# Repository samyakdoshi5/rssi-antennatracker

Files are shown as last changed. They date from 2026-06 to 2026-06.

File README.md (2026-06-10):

# RX5808 Diversity Antenna Tracker

Arduino firmware, PCB drafts, and printable enclosure files for an RX5808/RX58xx diversity receiver adapted into an RSSI-based pan tracker. The active firmware targets a 128x32 SSD1306 OLED and drives a continuous-rotation servo from the calibrated RSSI difference between two directional antennas.

## Repository Layout

| Path | Contents |
| --- | --- |
| `code/rx5808-pro-diversity-2.0/` | Active Arduino firmware and bundled legacy support libraries. |
| `code/rx5808-pro-diversity-2.0/rx5808-pro-diversity/` | Main sketch and source files. Open `rx5808-pro-diversity.ino` in the Arduino IDE. |
| `code/buttontest/` | Small standalone sketch for checking button wiring. |
| `pcb (draft)/` | Draft KiCad project and exported Gerber/drill files. |
| `v1/` to `v5/` | Mechanical enclosure revisions. `v5/` is the newest STL set. |

## Hardware

- Arduino-compatible AVR board
- Two RX5808/RX58xx receiver modules
- 128x32 SSD1306 I2C OLED
- Continuous-rotation 360 servo for pan movement
- Three firmware buttons: Up, Down, Mode
- Active buzzer
- Two directional antennas, with receiver A mounted left and receiver B mounted right

## Pin Map

| Function | Pin |
| --- | --- |
| Button Up | `2` |
| Button Down | `3` |
| Button Mode | `4` |
| Buzzer | `6` |
| Tracker servo | `7` |
| SPI data | `10` |
| SPI slave select | `11` |
| SPI clock | `12` |
| Board LED | `13` |
| Receiver A LED/control | `A0` |
| Receiver B LED/control | `A1` |
| Receiver A RSSI | `A7` |
| Receiver B RSSI | `A6` |

## Firmware Configuration

Main configuration lives in:

```text
code/rx5808-pro-diversity-2.0/rx5808-pro-diversity/settings.h
```

Current enabled options:

```cpp
#define OLED_128x32_ADAFRUIT_SCREENS
#define RX5808
#define USE_DIVERSITY
#define USE_DIVERSITY_FAST_SWITCHING
#define USE_SERIAL_OUT
#define USE_LBAND
```

The old screensaver state has been removed, and the UI has been compressed for the 128x32 OLED.

## Build Notes

Open this sketch in the Arduino IDE:

```text
code/rx5808-pro-diversity-2.0/rx5808-pro-diversity/rx5808-pro-diversity.ino
```

Required Arduino libraries:

- `Adafruit_SSD1306`
- `Adafruit_GFX`
- `Servo`

Bundled legacy libraries for TVout/pollserial are kept under `code/rx5808-pro-diversity-2.0/libraries/`. The current OLED build does not use TVout screens, but the files remain in the project history.

The sketch uses placement `new` through the standard `<new>` header. Do not add a custom placement `operator new`; newer Arduino cores already provide it and duplicate definitions can fail linking.

## Controls

- Hold `MODE` to open the menu.
- In the menu, use `UP` and `DOWN` to move between items.
- Short-press `MODE` to select the highlighted item.
- In tracker mode, short-press `MODE` to stop/recenter the servo command.

## Modes

- `Search`: normal channel search view.
- `Band Scan`: scans channels and draws RSSI history.
- `Tracker`: compares calibrated A/B RSSI and drives the pan servo.
- `Settings`: RSSI calibration entry point.

## Tracker Mode

Tracker mode assumes:

- Receiver `A` antenna points left.
- Receiver `B` antenna points right.
- A stronger calibrated `A` RSSI means the target is left.
- A stronger calibrated `B` RSSI means the target is right.

The tracker compares calibrated RSSI percentages, not raw ADC readings. This matters because two receiver modules often have different raw RSSI ranges.

The tracker display shows:

```text
A:cal/raw    B:cal/raw
winner       channel
PWM:us       direction graphic
```

Example:

```text
A:72/184     B:65/211
A LEFT       R1
PWM:1560     <----
```

## RSSI Calibration

Run RSSI calibration from `Settings` before using tracker mode.

The calibration stores independent min/max values for both modules:

- `rssiAMin`, `rssiAMax`
- `rssiBMin`, `rssiBMax`

The receiver code maps raw readings into calibrated `0..100` RSSI values. Tracker mode uses those calibrated values for decisions and only displays raw values for diagnosis.

## Servo Control

The tracker is set up for a continuous-rotation servo using microsecond pulses:

```cpp
#define TRACKER_SERVO_STOP_US 1500
#define TRACKER_SERVO_LEFT_MIN_US 1505
#define TRACKER_SERVO_LEFT_MAX_US 1850
#define TRACKER_SERVO_RIGHT_MIN_US 1495
#define TRACKER_SERVO_RIGHT_MAX_US 1150
```

Tune `TRACKER_SERVO_STOP_US` first. If the servo creeps while stopped, adjust it slightly, for example to `1490` or `1510`.

The min values define the deadband edge. Once the tracker decides to move, it will command at least:

- `TRACKER_SERVO_LEFT_MIN_US` when moving left
- `TRACKER_SERVO_RIGHT_MIN_US` when moving right

The max values cap top speed in each direction.

## Tracker Tuning

Main tracker parameters are in `settings.h`.

```cpp
#define TRACKER_RSSI_MOVE_THRESHOLD 10
#define TRACKER_RSSI_STOP_THRESHOLD 5
#define TRACKER_MOVE_INTERVAL 20
#define TRACKER_MAX_SPEED_OFFSET_US 350
#define TRACKER_SERVO_SMOOTH_INTERVAL 5
#define TRACKER_SERVO_SMOOTH_STEP_US 70
```

- `TRACKER_RSSI_MOVE_THRESHOLD`: calibrated RSSI percent difference needed to start moving.
- `TRACKER_RSSI_STOP_THRESHOLD`: calibrated RSSI percent difference where movement stops. Keep below the move threshold for hysteresis.
- `TRACKER_MOVE_INTERVAL`: PID target-speed update interval in ms.
- `TRACKER_MAX_SPEED_OFFSET_US`: max speed offset from neutral before direction caps.
- `TRACKER_SERVO_SMOOTH_INTERVAL`: how often the output pulse slews toward the target.
- `TRACKER_SERVO_SMOOTH_STEP_US`: max microsecond change per smoothing tick.

PID values:

```cpp
#define TRACKER_PID_KP 120
#define TRACKER_PID_KI 0
#define TRACKER_PID_KD 80
#define TRACKER_PID_SCALE 16
#define TRACKER_PID_INTEGRAL_MAX 80
```

- Raise `KP` for faster response to RSSI error.
- Keep `KI` at `0` unless you need persistent bias correction.
- Raise `KD` to damp overshoot when the error is shrinking.
- Raise `TRACKER_PID_SCALE` to make the whole PID output less aggressive.

## Serial Debug

Serial RSSI output is enabled:

```cpp
#define USE_SERIAL_OUT
```

Open Serial Monitor at `250000` baud. Output is tab-separated:

```text
channel    rssiA    rssiA_raw    rssiB    rssiB_raw
```

## Mechanical Files

The enclosure revisions are organized as `v1/` through `v5/`. The newest revision, `v5/`, contains:

- `mainshell.STL`
- `baselid.STL`
- `articulatedtop.STL`
- `antennaframe.STL`
- `hingepin.STL`

Earlier revisions include additional SolidWorks source files and intermediate STL/3MF exports.

## PCB Files

`pcb (draft)/` contains a draft KiCad project:

- `main.kicad_pro` — Project file
- `main.kicad_sch` — Schematic
- `main.kicad_pcb` — PCB layout

Treat this as a draft design until it has been checked against the latest mechanical and wiring changes. Manufacturing files (Gerber, drill, etc.) have not yet been exported.

## Quick Tuning Order

1. Flash `code/buttontest/buttontest.ino` if you need to verify button wiring.
2. Flash the main tracker sketch.
3. Tune `TRACKER_SERVO_STOP_US` until the servo does not creep.
4. Set `TRACKER_SERVO_LEFT_MIN_US` and `TRACKER_SERVO_RIGHT_MIN_US` just outside the servo deadband.
5. Run RSSI calibration.
6. If it chases noise, raise `TRACKER_RSSI_MOVE_THRESHOLD` and `TRACKER_RSSI_STOP_THRESHOLD`.
7. If it reacts too slowly, raise `TRACKER_PID_KP` or `TRACKER_MAX_SPEED_OFFSET_US`.
8. If it overshoots, raise `TRACKER_PID_KD` or lower `TRACKER_PID_KP`.

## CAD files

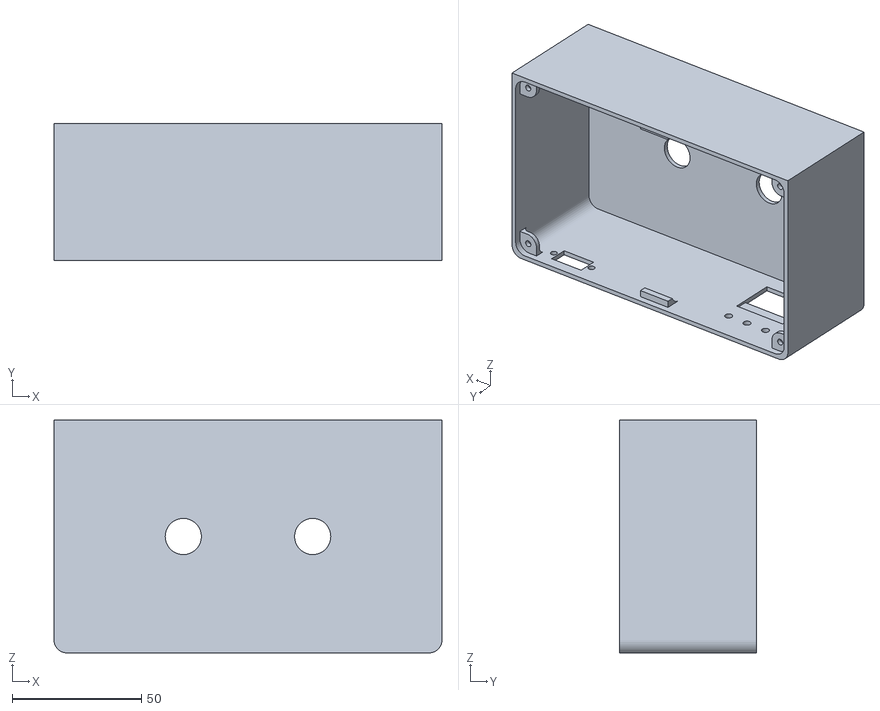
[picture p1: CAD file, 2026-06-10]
v5/mainshell.STL
150.0 x 53.0 x 90.0

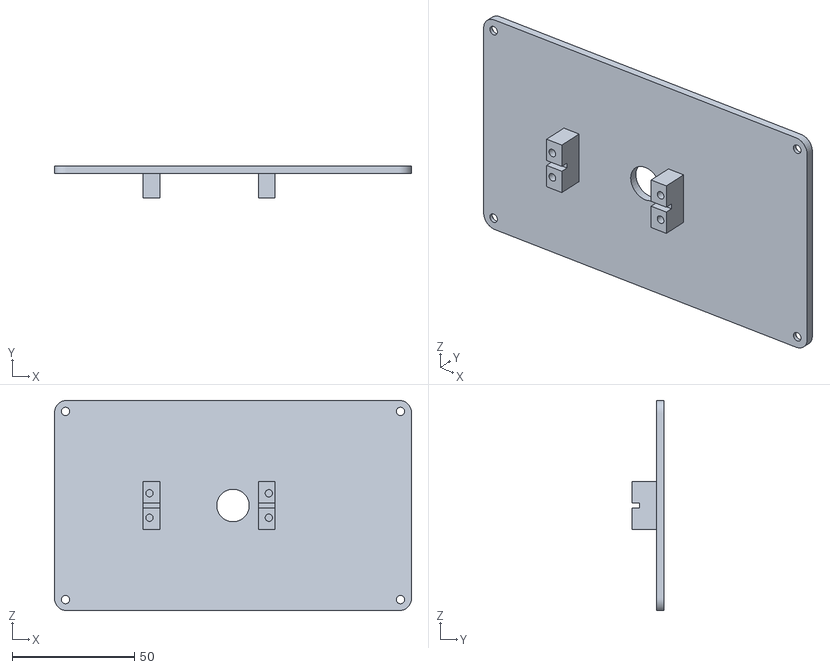
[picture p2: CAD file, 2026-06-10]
v5/baselid.STL
146.0 x 13.0 x 86.0

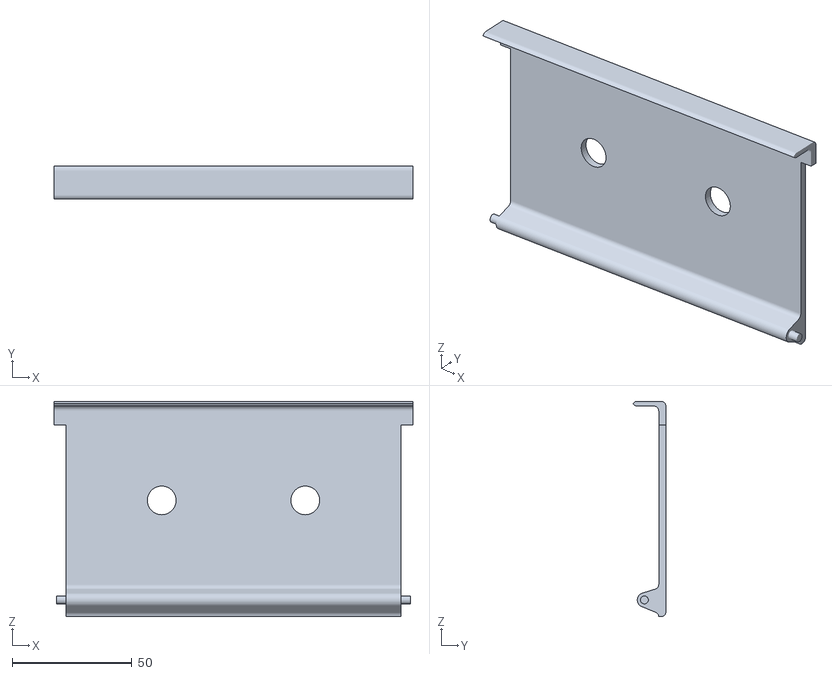
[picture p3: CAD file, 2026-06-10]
v5/articulatedtop.STL
150.0 x 13.7 x 90.0

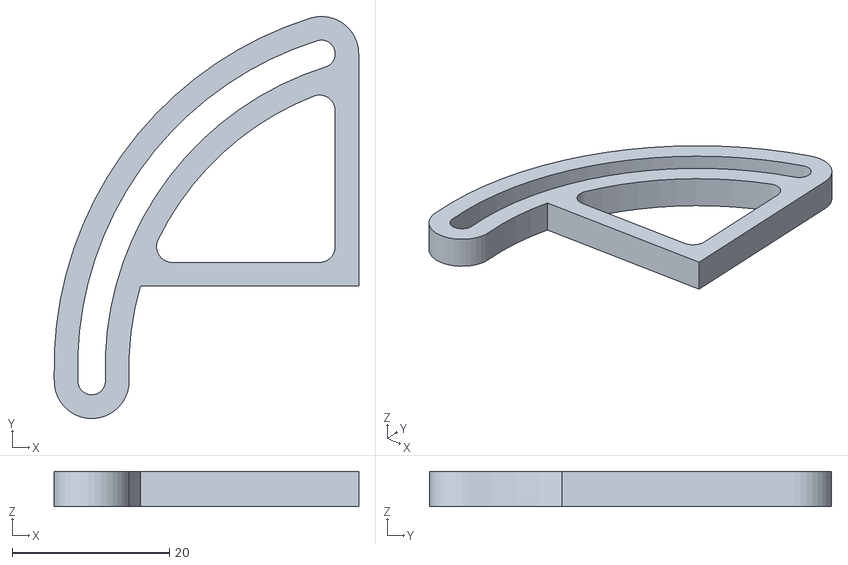
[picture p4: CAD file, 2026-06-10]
v5/hingepin.STL
38.7 x 51.1 x 4.50

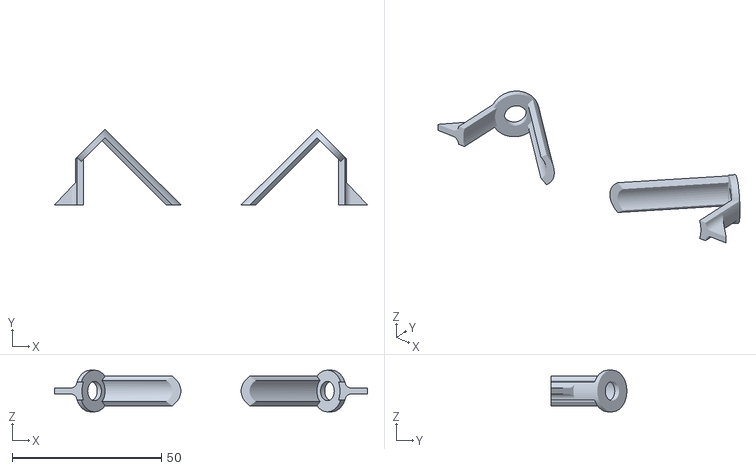
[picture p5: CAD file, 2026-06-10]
v5/antennaframe.STL
105.0 x 25.4 x 14.0

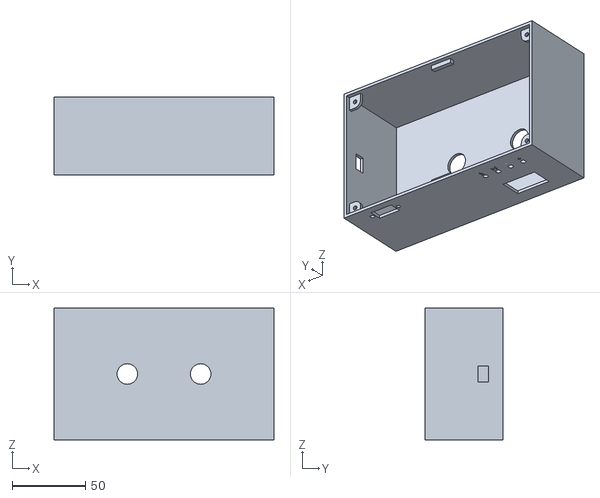
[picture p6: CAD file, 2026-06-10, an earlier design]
v3/mainshell.STL
150.0 x 53.0 x 90.0

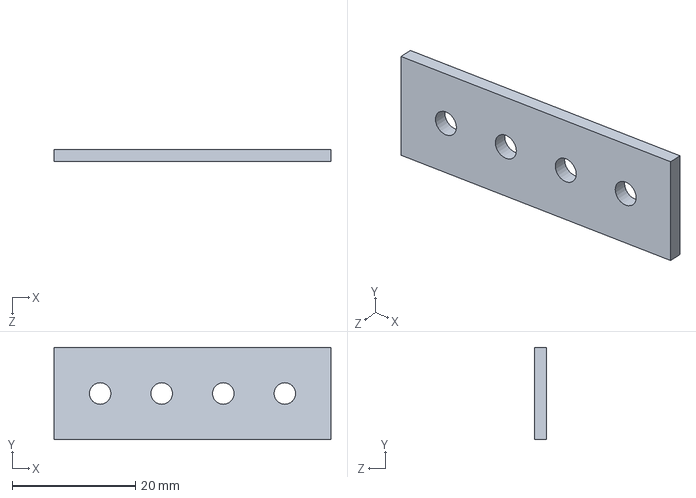
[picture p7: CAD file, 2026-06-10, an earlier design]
v1/buttonarray.SLDPRT
45.0 x 15.0 x 2.00 mm

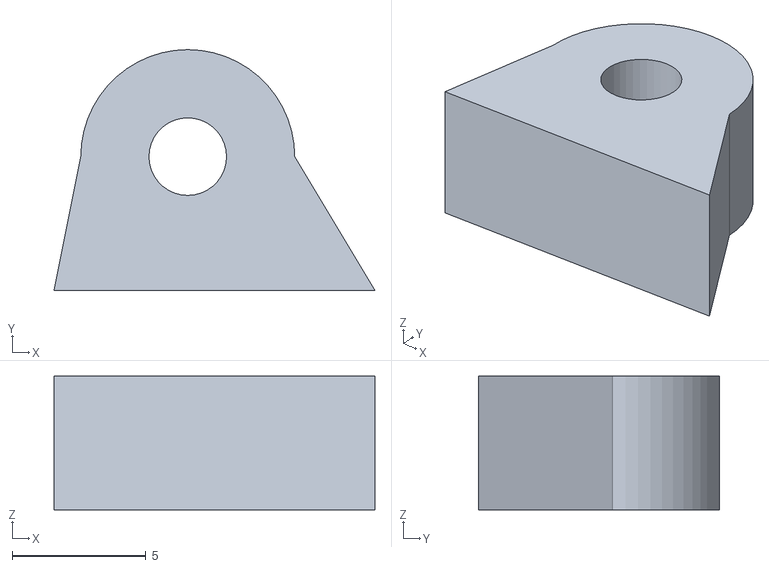
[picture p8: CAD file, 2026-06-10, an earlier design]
v2/hingepin.STL
12.0 x 9.00 x 5.00

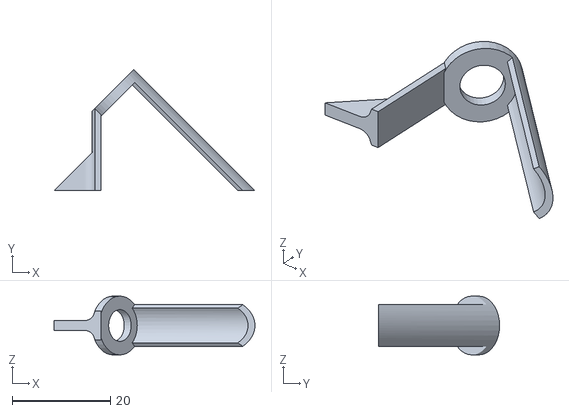
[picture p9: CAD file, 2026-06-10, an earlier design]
v3/antennaholder.STL
41.0 x 24.7 x 12.0

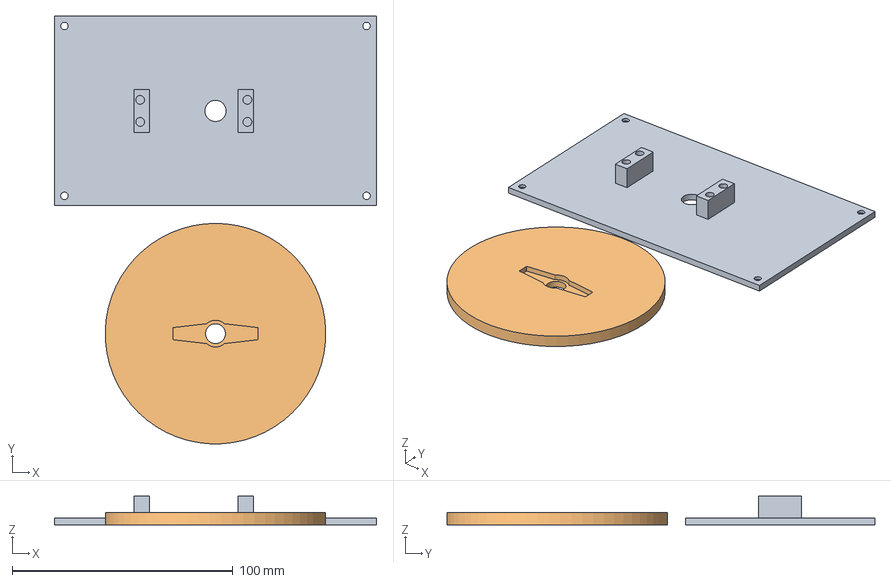
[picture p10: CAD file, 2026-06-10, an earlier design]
v4/base.3mf
146.0 x 194.0 x 13.0 mm
baselid.STL
base.STL

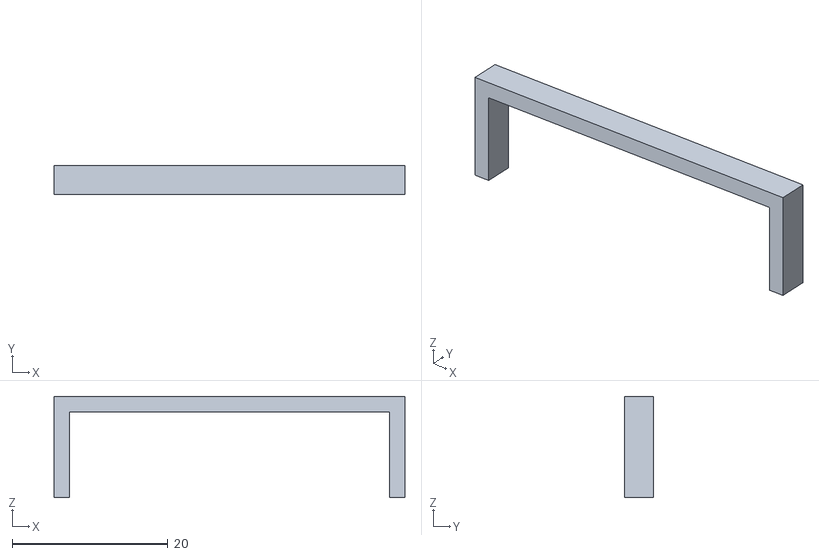
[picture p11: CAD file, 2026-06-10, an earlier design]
v2/buttonarrayriser.STL
45.0 x 3.75 x 13.0

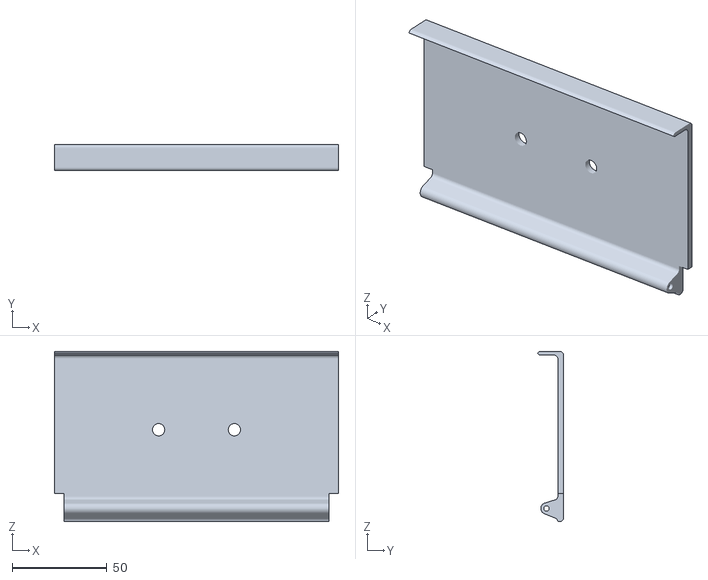
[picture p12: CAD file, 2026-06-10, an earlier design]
v2/articulatedtop.STL
150.0 x 13.7 x 90.0

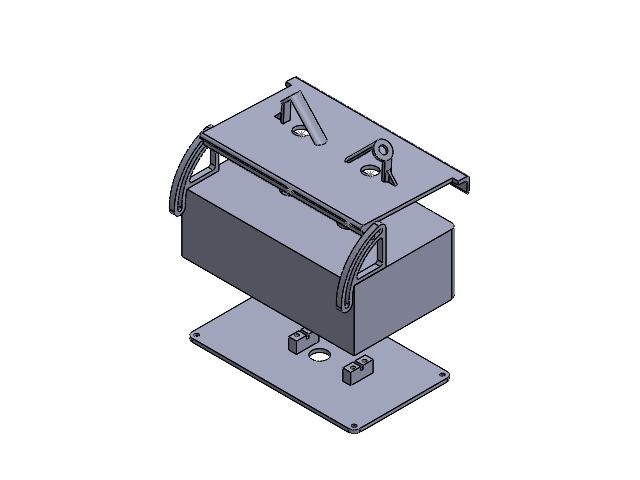
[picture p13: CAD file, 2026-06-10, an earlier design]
v1/assem.SLDASM
mainshell
baselid
articulatedtop
Display_OLED_0.96_128x64
hingepin x 2

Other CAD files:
v2/mainshell.STL
v1/mainshell.SLDPRT
v1/antennaframe.SLDPRT
v4/baselid.STL
v1/Body - Screen Border.SLDPRT.SLDPRT
v1/Body - Adhesive Pad.SLDPRT.SLDPRT
v1/Body - Back Panel.SLDPRT.SLDPRT
v1/Body - Black Tape.SLDPRT.SLDPRT
v1/Body - Flex Connector Bend.SLDPRT.SLDPRT
v1/Body - Flex Connector Terminals.SLDPRT.SLDPRT
v1/Body - Front Panel.SLDPRT.SLDPRT
v1/Body - PCB.SLDPRT.SLDPRT
v1/Body - Protective Foil.SLDPRT.SLDPRT
v1/Display_OLED_0.96_128x64.SLDPRT
v1/Extrude - Annular Rings.SLDPRT.SLDPRT
v1/accessory.SLDPRT
v1/articulatedtop.SLDPRT
v1/articulatedtop.STL
v1/baselid.SLDPRT
v1/baselid.STL
v1/buttonarrayriser.SLDPRT
v1/hingepin.SLDPRT
v1/hingepin.STL
v1/mainshell.STL
v2/baselid.STL
v2/buttonarray.STL
v2/servostandoff.SLDPRT
v2/servostandoff.STL
v3/articulatedtop.3mf
v3/articulatedtop.STL
v3/base.SLDPRT
v3/base.STL
v3/hingepin.STL
v4/base.STL

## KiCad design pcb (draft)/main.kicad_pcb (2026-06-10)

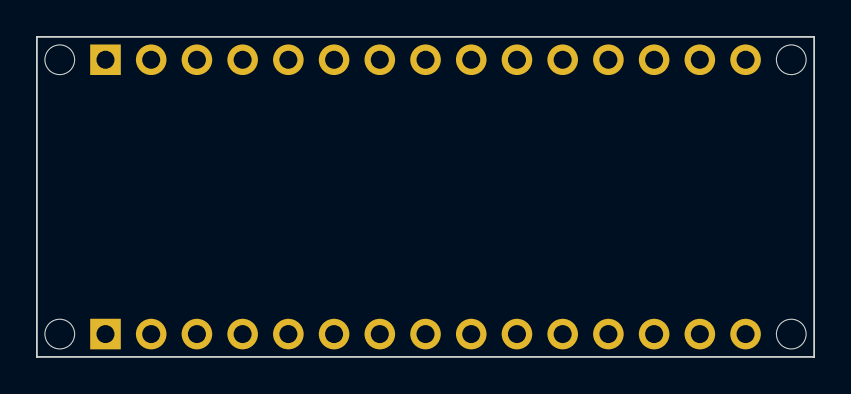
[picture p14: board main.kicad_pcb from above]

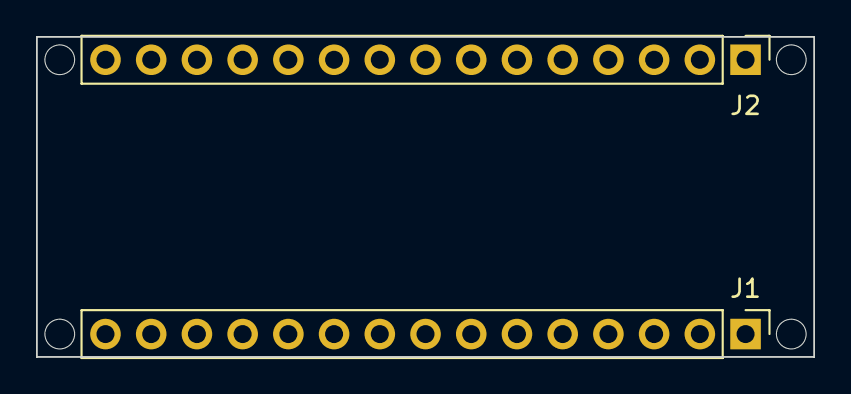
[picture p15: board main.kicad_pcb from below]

Board: 2 copper layers, 43.2 x 17.8 mm, 6 parts (2 on the bottom side), 2 nets, no tracks yet.

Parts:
J1: Analog; PinHeader_1x15_P2.54mm_Vertical
J2: Digital; PinHeader_1x15_P2.54mm_Vertical
MH1, MH2, MH3, MH4: MountingHole_65mil

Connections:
/~RESET: J1.13, J2.13
GND: J1.14, J2.12

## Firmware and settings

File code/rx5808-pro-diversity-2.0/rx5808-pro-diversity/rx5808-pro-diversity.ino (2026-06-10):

/*
 * SPI driver based on fs_skyrf_58g-main.c Written by Simon Chambers
 * TVOUT by Myles Metzel
 * Scanner by Johan Hermen
 * Inital 2 Button version by Peter (pete1990)
 * Refactored and GUI reworked by Marko Hoepken
 * Universal version my Marko Hoepken
 * Diversity Receiver Mode and GUI improvements by Shea Ivey
 * OLED Version by Shea Ivey
 * Seperating display concerns by Shea Ivey

The MIT License (MIT)

Copyright (c) 2015 Marko Hoepken

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
THE SOFTWARE IS PROVIDED "AS IS", WITHOUT WARRANTY OF ANY KIND, EXPRESS OR
IMPLIED, INCLUDING BUT NOT LIMITED TO THE WARRANTIES OF MERCHANTABILITY,
FITNESS FOR A PARTICULAR PURPOSE AND NONINFRINGEMENT. IN NO EVENT SHALL THE
AUTHORS OR COPYRIGHT HOLDERS BE LIABLE FOR ANY CLAIM, DAMAGES OR OTHER
LIABILITY, WHETHER IN AN ACTION OF CONTRACT, TORT OR OTHERWISE, ARISING FROM,
OUT OF OR IN CONNECTION WITH THE SOFTWARE OR THE USE OR OTHER DEALINGS IN THE
SOFTWARE.
*/


#include "settings.h"
#include "settings_internal.h"
#include "settings_eeprom.h"

#include "channels.h"
#include "receiver.h"
#include "receiver_spi.h"
#include "buttons.h"
#include "state.h"

#include "ui.h"


static void globalMenuButtonHandler(
    Button button,
    Buttons::PressType pressType
);


void setup()
{
    setupPins();

    // Enable buzzer and LED for duration of setup process.
    digitalWrite(PIN_LED, HIGH);
    digitalWrite(PIN_BUZZER, LOW);

    setupSettings();

    StateMachine::setup();
    Receiver::setup();
    Ui::setup();

    Receiver::setActiveReceiver(Receiver::ReceiverId::A);

    #ifdef USE_IR_EMITTER
        Serial.begin(9600);
    #endif
    #ifdef USE_SERIAL_OUT
        Serial.begin(250000);
    #endif

    // Setup complete.
    digitalWrite(PIN_LED, LOW);
    digitalWrite(PIN_BUZZER, HIGH);

    Buttons::registerChangeFunc(globalMenuButtonHandler);

    // Switch to initial state.
    StateMachine::switchState(StateMachine::State::SEARCH);
}

void setupPins() {
    pinMode(PIN_LED, OUTPUT);
    pinMode(PIN_BUZZER, OUTPUT);
    pinMode(PIN_BUTTON_UP, INPUT_PULLUP);
    pinMode(PIN_BUTTON_MODE, INPUT_PULLUP);
    pinMode(PIN_BUTTON_DOWN, INPUT_PULLUP);
    pinMode(PIN_TRACKER_SERVO, OUTPUT);

    pinMode(PIN_LED_A,OUTPUT);
    #ifdef USE_DIVERSITY
        pinMode(PIN_LED_B,OUTPUT);
    #endif

    pinMode(PIN_RSSI_A, INPUT_PULLUP);
    #ifdef USE_DIVERSITY
        pinMode(PIN_RSSI_B, INPUT_PULLUP);
    #endif

    pinMode(PIN_SPI_SLAVE_SELECT, OUTPUT);
    pinMode(PIN_SPI_DATA, OUTPUT);
	pinMode(PIN_SPI_CLOCK, OUTPUT);

    digitalWrite(PIN_SPI_SLAVE_SELECT, HIGH);
    digitalWrite(PIN_SPI_CLOCK, LOW);
    digitalWrite(PIN_SPI_DATA, LOW);
}

void setupSettings() {
    EepromSettings.load();
    Receiver::setChannel(EepromSettings.startChannel);
}


void loop() {
    Receiver::update();
    Buttons::update();
    StateMachine::update();
    Ui::update();
    EepromSettings.update();
}


static void globalMenuButtonHandler(
    Button button,
    Buttons::PressType pressType
) {
    if (
        StateMachine::currentState != StateMachine::State::MENU &&
        button == Button::MODE &&
        pressType == Buttons::PressType::HOLDING
    ) {
        StateMachine::switchState(StateMachine::State::MENU);
    }
}

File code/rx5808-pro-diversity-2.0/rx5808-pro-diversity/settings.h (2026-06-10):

/*
 * Setings file by Shea Ivey

The MIT License (MIT)

Copyright (c) 2015 Shea Ivey

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
THE SOFTWARE IS PROVIDED "AS IS", WITHOUT WARRANTY OF ANY KIND, EXPRESS OR
IMPLIED, INCLUDING BUT NOT LIMITED TO THE WARRANTIES OF MERCHANTABILITY,
FITNESS FOR A PARTICULAR PURPOSE AND NONINFRINGEMENT. IN NO EVENT SHALL THE
AUTHORS OR COPYRIGHT HOLDERS BE LIABLE FOR ANY CLAIM, DAMAGES OR OTHER
LIABILITY, WHETHER IN AN ACTION OF CONTRACT, TORT OR OTHERWISE, ARISING FROM,
OUT OF OR IN CONNECTION WITH THE SOFTWARE OR THE USE OR OTHER DEALINGS IN THE
SOFTWARE.
*/

#ifndef SETTINGS_H
#define SETTINGS_H


// === Display Module ==========================================================
//
// You can choose one display module only.
//
// =============================================================================

// SSH1106 needs https://github.com/badzz/Adafruit_SH1106 installed.
//#define SH1106

//#define TVOUT_SCREENS
//#define OLED_128x64_ADAFRUIT_SCREENS
#define OLED_128x32_ADAFRUIT_SCREENS

// Enable this if your screen is upside down.
//#define USE_FLIP_SCREEN

#if defined(OLED_128x64_ADAFRUIT_SCREENS) || defined(OLED_128x32_ADAFRUIT_SCREENS)
    #define OLED_ADDRESS 0x3C // I2C address for display (0x3C or 0x3D, usually)
#endif

// === Receiver Module =========================================================
//
// Select which receiever you are using. Required for time tuning.
//
// =============================================================================

#define RX5808
//#define RX5880

// Can enable this to powerdown the audio blocks on the RX58xx if you don't
// need it. Save a tiny bit of power, make your videos less noisy.
//
// WARNING: Makes RSSI act a little weird.
//#define DISABLE_AUDIO

// === Features ===============================================================
//
// Keep in mind that there is limited program memory. Only enable the features
// you need.
//
// =============================================================================

#define USE_DIVERSITY

// Enable this to switch receivers much faster. This uses the port registers
// to switch rather than the Arduino helper functions.
//
// WARNING: You can only use this if your receivers are on the same port.
// Arduino/ATmega has 3 ports: PORTD, PORTB, and PORTC. The "default" hardware
// configuration uses pins A0 and A1 (PORTC), so if you're using reasonably
// standard hardware then this should be fine.
//
// PORTC: Pins A0-A7
// PORTD: 0-7
// PORTB: 8-13
#define USE_DIVERSITY_FAST_SWITCHING

//#define USE_IR_EMITTER
#define USE_SERIAL_OUT // Not compatible with IR emitter.

// You can use any of the arduino analog pins to measure the voltage of the
// battery. See additional configuration below.
//#define USE_VOLTAGE_MONITORING

// Choose if you wish to use 8 additional channels:
//     5362 MHz
//     5399 MHz
//     5436 MHz
//     5473 MHz
//     5510 MHz
//     5547 MHz
//     5584 MHz
//     5621 MHz
// Local laws may prohibit the use of these frequencies so use at your own risk!
#define USE_LBAND

// === Pins ====================================================================

// Buttons (required)
#define PIN_BUTTON_UP 2
#define PIN_BUTTON_MODE 4

// Buttons (optional, for comfort)
#define PIN_BUTTON_DOWN 3

#define PIN_LED 13
#define PIN_BUZZER 6 // Must be an active buzzer, not passive.
#define PIN_TRACKER_SERVO 7

#define PIN_SPI_DATA 10
#define PIN_SPI_SLAVE_SELECT 11
#define PIN_SPI_CLOCK 12

#define PIN_RSSI_A A7
#define PIN_LED_A A0
#ifdef USE_DIVERSITY
    #define PIN_LED_B A1
    #define PIN_RSSI_B A6
#endif

#ifdef USE_VOLTAGE_MONITORING
    #ifdef TVOUT_SCREENS
        #define PIN_VBAT A4
    #else
        #define PIN_VBAT A2
    #endif
#endif

// === Diversity ===============================================================

#ifdef USE_DIVERSITY
    // RSSI strength should be greater than the value below (percent) over the
    // other receiver before we switch. This pervents flicker when RSSI values
    // are close and delays diversity checks counter.
    #define DIVERSITY_HYSTERESIS 2

    // How long (ms) the RSSI strength has to have a greater difference than the
    // above before switching.
    #define DIVERSITY_HYSTERESIS_PERIOD 5
#endif

// === Voltage Monitoring ======================================================
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

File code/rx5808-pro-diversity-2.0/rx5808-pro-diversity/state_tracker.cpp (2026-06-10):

#include <Arduino.h>
#include <stdlib.h>

#include "state_tracker.h"

#include "channels.h"
#include "receiver.h"
#include "settings.h"
#include "ui.h"
#include "pstr_helper.h"


using StateMachine::TrackerStateHandler;


void TrackerStateHandler::onEnter() {
    filteredDiff = 0;
    lastError = 0;
    errorIntegral = 0;
    moveDirection = MoveDirection::STOP;
    servoPwm = TRACKER_SERVO_STOP_US;
    targetPwm = TRACKER_SERVO_STOP_US;
    panServo.attach(PIN_TRACKER_SERVO);
    panServo.writeMicroseconds(servoPwm);
    moveTimer.reset();
    servoTimer.reset();
}

void TrackerStateHandler::onExit() {
    panServo.detach();
}

void TrackerStateHandler::onUpdate() {
#ifdef USE_DIVERSITY
    if (Receiver::isRssiStable()) {
        const int16_t calibratedDiff =
            (int16_t)Receiver::rssiA - (int16_t)Receiver::rssiB;
        filteredDiff = (filteredDiff + calibratedDiff) / 2;

        updateDirection();
        updateServoTargetPwm();
    }

    smoothServo();
    Ui::needUpdate();
#endif
}

void TrackerStateHandler::updateDirection() {
    const int16_t absDiff = abs(filteredDiff);
    MoveDirection nextDirection = moveDirection;

    if (absDiff <= TRACKER_RSSI_STOP_THRESHOLD) {
        moveDirection = MoveDirection::STOP;
        lastError = filteredDiff;
        errorIntegral = 0;
        return;
    }

    if (filteredDiff >= TRACKER_RSSI_MOVE_THRESHOLD) {
        nextDirection = MoveDirection::LEFT;
    } else if (filteredDiff <= -TRACKER_RSSI_MOVE_THRESHOLD) {
        nextDirection = MoveDirection::RIGHT;
    }

    if (nextDirection != moveDirection) {
        lastError = filteredDiff;
        errorIntegral = 0;
    }

    moveDirection = nextDirection;
}

void TrackerStateHandler::updateServoTargetPwm() {
    if (moveDirection == MoveDirection::STOP) {
        targetPwm = TRACKER_SERVO_STOP_US;
        return;
    }

    if (!moveTimer.hasTicked())
        return;

    const uint16_t offset = speedOffset();

    if (moveDirection == MoveDirection::LEFT) {
        targetPwm = TRACKER_SERVO_STOP_US + offset;
        if (targetPwm < TRACKER_SERVO_LEFT_MIN_US)
            targetPwm = TRACKER_SERVO_LEFT_MIN_US;
        if (targetPwm > TRACKER_SERVO_LEFT_MAX_US)
            targetPwm = TRACKER_SERVO_LEFT_MAX_US;
    } else {
        targetPwm = TRACKER_SERVO_STOP_US - offset;
        if (targetPwm > TRACKER_SERVO_RIGHT_MIN_US)
            targetPwm = TRACKER_SERVO_RIGHT_MIN_US;
        if (targetPwm < TRACKER_SERVO_RIGHT_MAX_US)
            targetPwm = TRACKER_SERVO_RIGHT_MAX_US;
    }

    moveTimer.reset();
}

void TrackerStateHandler::smoothServo() {
    if (servoPwm == targetPwm || !servoTimer.hasTicked())
        return;

    if (servoPwm < targetPwm) {
        servoPwm =
            servoPwm + TRACKER_SERVO_SMOOTH_STEP_US < targetPwm ?
            servoPwm + TRACKER_SERVO_SMOOTH_STEP_US :
            targetPwm;
    } else {
        servoPwm =
            servoPwm > targetPwm + TRACKER_SERVO_SMOOTH_STEP_US ?
            servoPwm - TRACKER_SERVO_SMOOTH_STEP_US :
            targetPwm;
    }

    panServo.writeMicroseconds(servoPwm);
    servoTimer.reset();
}

uint16_t TrackerStateHandler::speedOffset() {
    const int16_t error = abs(filteredDiff);
    const int16_t derivative = error - abs(lastError);

    errorIntegral += error;
    if (errorIntegral > TRACKER_PID_INTEGRAL_MAX)
        errorIntegral = TRACKER_PID_INTEGRAL_MAX;

    int32_t pidOutput =
        ((int32_t)TRACKER_PID_KP * error) +
        ((int32_t)TRACKER_PID_KI * errorIntegral) +
        ((int32_t)TRACKER_PID_KD * derivative);

    lastError = filteredDiff;

    if (pidOutput < TRACKER_PID_SCALE)
        pidOutput = TRACKER_PID_SCALE;

    uint16_t offset = pidOutput / TRACKER_PID_SCALE;
    if (offset < 1)
        offset = 1;
    if (offset > TRACKER_MAX_SPEED_OFFSET_US)
        offset = TRACKER_MAX_SPEED_OFFSET_US;

    return offset;
}

void TrackerStateHandler::onInitialDraw() {
    Ui::clear();
    onUpdateDraw();
}

void TrackerStateHandler::onUpdateDraw() {
    Ui::clear();

#ifdef USE_DIVERSITY
    drawRssiText();
    drawWinnerText();
    drawDirectionGraphic();
#else
    Ui::display.setTextSize(1);
    Ui::display.setTextColor(WHITE);
    Ui::display.setCursor(0, 0);
    Ui::display.print(PSTR2("Tracker needs"));
    Ui::display.setCursor(0, 10);
    Ui::display.print(PSTR2("USE_DIVERSITY"));
#endif

    Ui::needDisplay();
}

void TrackerStateHandler::drawRssiText() {
#ifdef USE_DIVERSITY
    Ui::display.setTextSize(1);
    Ui::display.setTextColor(WHITE);
    Ui::display.setCursor(0, 0);
    Ui::display.print(PSTR2("A:"));
    Ui::display.print(Receiver::rssiA);
    Ui::display.print(PSTR2("/"));
    Ui::display.print(Receiver::rssiARaw);

    Ui::display.setCursor(64, 0);
    Ui::display.print(PSTR2("B:"));
    Ui::display.print(Receiver::rssiB);
    Ui::display.print(PSTR2("/"));
    Ui::display.print(Receiver::rssiBRaw);
#endif
}

void TrackerStateHandler::drawWinnerText() {
    Ui::display.setCursor(0, 10);

    if (filteredDiff > TRACKER_RSSI_STOP_THRESHOLD) {
        Ui::display.print(PSTR2("A LEFT"));
    } else if (filteredDiff < -TRACKER_RSSI_STOP_THRESHOLD) {
        Ui::display.print(PSTR2("B RIGHT"));
    } else {
        Ui::display.print(PSTR2("BALANCED"));
    }

    Ui::display.setCursor(76, 10);
    Ui::display.print(Channels::getName(Receiver::activeChannel));
}

void TrackerStateHandler::drawDirectionGraphic() {
    const uint8_t y = 24;
    const uint8_t centerX = SCREEN_WIDTH_MID;

    Ui::display.setCursor(0, 21);
    Ui::display.print(PSTR2("PWM:"));
    Ui::display.print(servoPwm);

    Ui::display.drawFastHLine(46, y, SCREEN_WIDTH - 58, WHITE);
    Ui::display.drawFastVLine(centerX, y - 4, 9, WHITE);

    if (moveDirection == MoveDirection::LEFT) {
        Ui::display.fillTriangle(48, y, 56, y - 4, 56, y + 4, WHITE);
        Ui::display.drawFastHLine(56, y, centerX - 56, WHITE);
    } else if (moveDirection == MoveDirection::RIGHT) {
        Ui::display.fillTriangle(
            SCREEN_WIDTH - 12,
            y,
            SCREEN_WIDTH - 22,
            y - 4,
            SCREEN_WIDTH - 22,
            y + 4,
            WHITE
        );
        Ui::display.drawFastHLine(
            centerX + 1,
            y,
            SCREEN_WIDTH - centerX - 23,
            WHITE
        );
    } else {
        Ui::display.fillRect(centerX - 2, y - 2, 5, 5, WHITE);
    }
}

void TrackerStateHandler::onButtonChange(
    Button button,
    Buttons::PressType pressType
) {
    if (button == Button::MODE && pressType == Buttons::PressType::SHORT) {
        servoPwm = TRACKER_SERVO_STOP_US;
        targetPwm = TRACKER_SERVO_STOP_US;
        panServo.writeMicroseconds(servoPwm);
        moveDirection = MoveDirection::STOP;
        filteredDiff = 0;
        lastError = 0;
        errorIntegral = 0;
        Ui::needUpdate();
    }
}

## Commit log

2026-06-10 removed save button
2026-06-10 cleaned structure
    [main.kicad_pcb, main.kicad_sch, untitled.kicad_pcb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]
2026-06-10 removed scrap files
    [main.kicad_pcb, main.kicad_sch, untitled.kicad_pcb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]
